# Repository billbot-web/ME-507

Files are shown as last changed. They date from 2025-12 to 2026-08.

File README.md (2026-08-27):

# SportTrackr: Camera-Guided Dual-Axis Tracking System

An ESP32-based real-time tracking system that combines computer vision, motion control, and web telemetry to automatically track LED targets using a camera-guided pan-tilt mechanism.

System Overview

## Project Overview

SportTrackr is an embedded control system designed for automated visual tracking applications. The system uses an OV5640 camera module for target detection, dual DC motors with encoders for precise pan-tilt control, and an IMU for orientation sensing. All components are coordinated through a FreeRTOS-based task architecture with PID control loops for smooth and accurate tracking.

### Key Features

- **Autonomous LED Tracking**: Real-time computer vision processing for target detection and tracking
- **Multi-Mode Operation**: Automatic tracking, manual control, velocity mode, and position mode
- **Web Interface**: Live telemetry streaming and remote control via WiFi
- **Precision Control**: Closed-loop PID control with encoder feedback
- **Sensor Fusion**: 9-DOF IMU integration for enhanced stability
- **Modular Architecture**: FSM-based task design for easy extension and debugging

## 📁 Repository Structure

```
├── data/              # Web UI assets (HTML, CSS, JavaScript)
├── docs/              # Doxygen-generated documentation
├── src/               # Source code
│   ├── hardware/      # Hardware drivers (motors, encoders, camera, IMU)
│   ├── tasks/         # FreeRTOS task implementations
│   ├── fsm/           # Finite state machine framework
│   └── main.cpp       # System initialization and setup
└── hardware/          # Physical design files
    ├── cad/           # Mechanical CAD files (SolidWorks)
    └── pcb/           # PCB design files (KiCad)
```

## System Components

### Hardware
- **MCU**: ESP32-WROVER (Dual-core, WiFi, 4MB PSRAM)
- **Camera**: OV5640 (5MP, autofocus, JPEG compression)
- **Motors**: 2× DC motors with 70:1 gearboxes
- **Drivers**: 2× DRV8833 dual H-bridge motor controllers
- **Encoders**: 2× Quadrature encoders (64 CPR)
- **IMU**: BNO055 (9-DOF: accelerometer, gyroscope, magnetometer)

### Software Stack
- **Framework**: Arduino/ESP-IDF on PlatformIO
- **RTOS**: FreeRTOS for multitasking
- **Web Server**: ESPAsyncWebServer for WiFi interface
- **Control**: Custom PID implementation with multiple tuning profiles

## Documentation

Detailed documentation is available for each subsystem:

- **[Mechanical Design](hardware/cad/README.md)** - CAD models, assemblies, and 3D-printed parts
- **[Electronic Design](hardware/pcb/README.md)** - PCB schematics, board layout, and wiring
- **[Software Architecture](src/README.md)** - Code organization and design patterns
  - [Hardware Drivers](src/hardware/README.md) - Low-level peripheral interfaces
  - [Task Controllers](src/tasks/README.md) - FreeRTOS task implementations
  - [FSM Framework](src/fsm/README.md) - State machine design pattern
- **[Web Interface](data/README.md)** - User interface and telemetry system
- **[API Reference](docs/html/index.html)** - Full Doxygen documentation

## Getting Started

### Prerequisites
- PlatformIO IDE (VS Code extension recommended)
- ESP32 toolchain
- USB-to-Serial driver for ESP32

### Build and Upload
```bash
# Clone the repository
git clone https://github.com/billbot-web/ME-507.git
cd ME-507

# Build the project
pio run

# Upload to ESP32
pio run --target upload

# Upload filesystem (web UI)
pio run --target uploadfs

# Monitor serial output
pio device monitor
```

### Configuration
1. Update WiFi credentials in `src/tasks/UITask.cpp`
2. Adjust PID tuning parameters in `src/main.cpp` (see comments for guidance)
3. Calibrate camera detection thresholds in `src/tasks/CameraTask.cpp`

## Operating Modes

The system supports four distinct operating modes:

1. **TRACKER**: Autonomous camera-based target tracking with PID control
2. **TELEOP**: Manual velocity control via web interface
3. **MOTOR_TEST**: Open-loop motor testing for diagnostics
4. **CALIBRATE**: Encoder homing and reference position setup

Modes are switched via the web interface or programmatically through the ControllerTask.

## System Architecture

The system uses a modular FreeRTOS task architecture:

- **MotorTask** (2 instances): Multi-mode motor control with FSM-based state management
- **EncoderTask** (2 instances): High-frequency position/velocity measurement using ESP32 PCNT
- **ControllerTask**: System coordinator and mode manager
- **CameraTask**: Computer vision processing for LED detection
- **IMUTask**: Orientation sensing and sensor data fusion
- **UITask**: Web server, telemetry streaming, and user commands

Tasks communicate via FreeRTOS queues and share data through thread-safe mechanisms.

## Performance

- **Control Loop Rate**: 100 Hz (10ms task periods)
- **Camera Frame Rate**: ~10-15 FPS (JPEG compression)
- **Encoder Resolution**: 4480 counts/revolution (with gearbox)
- **Position Accuracy**: ±0.5° typical
- **Latency**: <50ms from detection to motor response

## Contributors

- **Johnny Rourke** - Software, Integration, Mechanical Design & CAD
- **William Hawkins** - Software, Electronics & PCB Design

## License

This project was developed as part of ME 507 (Mechatronics) at California Polytechnic State University, San Luis Obispo.

## 🔗 Additional Resources

- [Doxygen Documentation](docs/html/index.html) - Complete API reference
- [FSM Design Pattern](src/fsm/FSM.md) - State machine implementation details
- [PID Tuning Guide](src/main.cpp) - Controller configuration instructions

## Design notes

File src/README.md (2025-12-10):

# Software Architecture

This directory contains all source code for the SportTrackr embedded control system, organized into three main subsystems: hardware drivers, FreeRTOS tasks, and FSM framework.

## Directory Structure

```
src/
├── hardware/          # Low-level peripheral drivers
│   ├── DRV883.cpp/h           - Motor driver interface
│   ├── Encoder.cpp/h          - Quadrature encoder driver
│   ├── OV5640_camera.cpp/h    - Camera module interface
│   └── Adafruit_BNO055.cpp/h  - IMU sensor driver
├── tasks/             # FreeRTOS task controllers
│   ├── MotorTask.cpp/h        - Multi-mode motor control FSM
│   ├── EncoderTask.cpp/h      - Position/velocity measurement
│   ├── CameraTask.cpp/h       - Computer vision processing
│   ├── ControllerTask.cpp/h   - System coordinator
│   ├── UITask.cpp/h           - Web server & telemetry
│   └── IMU_TASK.cpp/h         - Inertial measurement
├── fsm/               # Finite state machine framework
│   ├── FSM.cpp/h              - State machine engine
│   ├── State.h                - State base class
│   └── FSM.md                 - Design documentation
└── main.cpp           # System initialization & setup
```
## Task Diagram
SportTrackr_TaskDiagram
## Inter-Task Communication

### Queue-Based Messaging and Shares, a length-one Queue
See the provided ME 507 library for more information
```cpp
// Create queues in main.cpp
QueueHandle_t motor_cmd_queue = xQueueCreate(10, sizeof(MotorCommand));
QueueHandle_t tracking_error_queue = xQueueCreate(5, sizeof(TrackingError));

// Producer (CameraTask)
TrackingError error;
error.x_error = led_x - FRAME_CENTER_X;
error.y_error = led_y - FRAME_CENTER_Y;
xQueueSend(tracking_error_queue, &error, 0);

// Consumer (MotorTask)
TrackingError error;
if (xQueueReceive(tracking_error_queue, &error, 0) == pdTRUE) {
    set_target_position(current_pos + error.x_error);
}
```

## Architecture Overview

### Design Philosophy
The system follows a **modular, task-based architecture** using FreeRTOS for concurrency and finite state machines for complex behavioral control. Each major subsystem runs as an independent task with well-defined responsibilities and communication interfaces.

### Key Principles
- **Separation of Concerns**: Hardware drivers are isolated from application logic
- **State-Driven Behavior**: Complex control modes managed via FSM pattern
- **Thread-Safe Communication**: FreeRTOS queues and shared data structures
- **Real-Time Responsiveness**: Fixed-period tasks with predictable timing
- **Modularity**: Easy to add/remove features without affecting other subsystems

## System Components

### 1. Hardware Drivers (`hardware/`)
Low-level peripheral interfaces providing abstraction over ESP32 hardware features.

**[Full Hardware Documentation →](hardware/README.md)**

- **DRV883**: H-bridge motor driver control (PWM, direction, sleep)
- **Encoder**: PCNT-based quadrature decoder for position/velocity
- **OV5640_camera**: Image capture, JPEG compression, LED detection
- **Adafruit_BNO055**: 9-DOF IMU with sensor fusion

### 2. Task Controllers (`tasks/`)
FreeRTOS tasks implementing system behaviors and coordination.

**[Full Task Documentation →](tasks/README.md)**

- **MotorTask**: FSM-based motor control (velocity, position, camera, test modes)
- **EncoderTask**: High-frequency encoder sampling and velocity estimation
- **CameraTask**: LED blob detection and visual servoing error computation
- **ControllerTask**: Global mode management and task coordination
- **UITask**: Web server, WebSocket telemetry, command processing
- **IMU_TASK**: Orientation sensing and motion data acquisition

### 3. FSM Framework (`fsm/`)
Reusable finite state machine implementation for behavioral control.

**[Full FSM Documentation →](fsm/README.md)**

- **FSM**: Execute-driven state machine engine
- **State**: Base class for state definitions
- **Usage**: Task behaviors modeled as state transitions

## 🔄 Data Flow

```
┌─────────────┐         ┌──────────────┐         ┌─────────────┐
│   Camera    │────────▶│  CameraTask  │────────▶│  MotorTask  │
│   (OV5640)  │  Image  │  (CV Loop)   │ Error   │  (Control)  │
└─────────────┘         └──────────────┘         └─────────────┘
                                                         │
                                                         │ PWM
                                                         ▼
┌─────────────┐         ┌──────────────┐         ┌─────────────┐
│   Encoder   │◀────────│ EncoderTask  │◀────────│  DRV8833    │
│   (PCNT)    │Position │ (Feedback)   │         │  (Driver)   │
└─────────────┘         └──────────────┘         └─────────────┘
                               │
                               │ Telemetry
                               ▼
┌─────────────┐         ┌──────────────┐         ┌─────────────┐
│   WiFi      │◀────────│   UITask     │◀────────│ Controller  │
│  (WebUI)    │WebSocket│  (Server)    │Commands │   Task      │
└─────────────┘         └──────────────┘         └─────────────┘
```

## Development Guide

### Building the Project
```bash
# Full build
pio run

# Upload firmware
pio run --target upload

# Upload web interface files
pio run --target uploadfs

# Serial monitor
pio device monitor
```

### Code Style
- **Doxygen Comments**: All functions, classes, and files documented
- **Naming Conventions**: 
  - Classes: `PascalCase`
  - Functions: `snake_case()`
  - Constants: `UPPER_SNAKE_CASE`
- **Indentation**: 4 spaces (no tabs)
- **Line Length**: 100 characters recommended

### Adding New Features

#### 1. New Hardware Driver
```cpp
// In src/hardware/NewDriver.h
class NewDriver {
public:
    NewDriver(int pin);
    void init();
    int read();
};

// Register in main.cpp
NewDriver driver(GPIO_PIN);
driver.init();
```

#### 2. New Task
```cpp
// In src/tasks/NewTask.h
class NewTask : public Task {
public:
    NewTask(const char* name, uint32_t stack, uint8_t priority);
    void run(void* params) override;
};

// Create in main.cpp
NewTask* newTask = new NewTask("NewTask", 4096, 3);
newTask->begin();
```

#### 3. New FSM State
```cpp
// Define state function
int new_state_execute() {
    // State behavior
    return NEXT_STATE_ID;  // or same ID to stay
}

// Add to state table
State newState(STATE_ID, "NEW_STATE", new_state_execute);
State* states[] = {&state0, &newState, ...};
```

## Debugging

### Serial Debugging
```cpp
Serial.println("Debug message");
Serial.printf("Value: %d\n", variable);
```

### Task Monitoring
```cpp
// In any task
void run(void* params) {
    while (1) {
        Serial.printf("[%s] Running at %lu\n", 
                      pcTaskGetName(NULL), 
                      xTaskGetTickCount());
        vTaskDelay(pdMS_TO_TICKS(10));
    }
}
```

### Common Issues

**Task Crashes**
- Increase stack size in task constructor
- Check for stack overflow with `uxTaskGetStackHighWaterMark()`
- Verify no blocking operations in ISRs

**Queue Overflows**
- Increase queue depth when creating
- Check consumer task is reading fast enough
- Add queue full error handling

**Timing Issues**
- Use `vTaskDelay()` not `delay()` in tasks
- Verify task priorities are appropriate
- Check for priority inversion on shared resources

## 📊 Performance Metrics

- **Control Loop**: 100 Hz (10ms period)
- **Camera Processing**: ~15 FPS
- **Encoder Sampling**: 1000 Hz
- **WebSocket Updates**: 10 Hz
- **CPU Utilization**: ~60% average (dual-core)
- **Memory Usage**: ~180KB RAM (PSRAM for camera)

## 🔧 Configuration

### WiFi Settings
Edit `src/tasks/UITask.cpp`:
```cpp
const char* ssid = "YourNetworkName";
const char* password = "YourPassword";
```

### PID Tuning
Edit `src/main.cpp`:
```cpp
// Position control
pidKp = 0.5f;
pidKi = 0.0f;
pidKd = 0.1f;

// Camera tracking
pidKp_cam = 0.3f;
pidKi_cam = 0.0f;
pidKd_cam = 0.05f;
```

### Camera Detection
Edit `src/tasks/CameraTask.cpp`:
```cpp
// HSV thresholds for LED detection
int hue_min = 160;
int hue_max = 180;
int sat_min = 100;
int val_min = 100;
```

## API Documentation

Complete Doxygen-generated API documentation is available at:
**[docs/html/index.html](../docs/html/index.html)**

Key documentation sections:
- Class hierarchy and inheritance
- Function prototypes and parameters
- File dependencies and includes
- Global variables and defines

## Testing

### Unit Testing
(Future: Add unit test framework)

### Integration Testing
1. **Motor Test Mode**: Verify PWM outputs and direction control
2. **Encoder Test**: Check position counting and velocity calculation
3. **Camera Test**: Validate LED detection accuracy
4. **Network Test**: Confirm WiFi connectivity and WebSocket streaming

### System Validation
- Run full tracking demo
- Verify mode transitions
- Check error handling and recovery
- Measure control loop timing

## Safety Features

- **Watchdog Timer**: Reset on task deadlock
- **Motor Current Limiting**: DRV8833 thermal protection
- **Bounds Checking**: Encoder position limits
- **Command Validation**: Web interface input sanitization
- **Fault Recovery**: Automatic restart on critical errors

## Support

For software architecture questions, implementation details, or bug reports:
- Review existing [Doxygen documentation](../docs/html/index.html)
- Check [FSM design patterns](fsm/FSM.md)
- See specific subsystem READMEs:
  - [Hardware Drivers](hardware/README.md)
  - [Task Controllers](tasks/README.md)
  - [FSM Framework](fsm/README.md)

## Future Enhancements

Potential improvements and extensions:
- [ ] Kalman filter for sensor fusion
- [ ] Design a better IR Transmitter
- [ ] Smooth the pan and tilt error from the camera
- [ ] Machine learning-based detection
- [ ] Bluetooth remote control
- [ ] SD card data logging
- [ ] OTA firmware updates
- [ ] Enhanced calibration routines

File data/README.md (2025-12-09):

# Web User Interface

This directory contains all web interface assets for the SportTrackr remote control and telemetry system. The UI provides real-time monitoring, manual control, and system configuration through a responsive web interface served by the ESP32.

## 📂 Directory Structure

```
data/
├── index.html         # Main web application
├── css/
│   └── style.css     # Styling and layout
└── js/
    └── app.js        # Client-side JavaScript logic
```

## 🌐 Overview

The SportTrackr web interface is a single-page application (SPA) that communicates with the ESP32 over WiFi using HTTP for initial page load and WebSockets for real-time bidirectional communication.

### Features
- **Live Telemetry Dashboard**: Real-time display of motor positions, velocities, IMU data
- **Mode Selection**: Switch between tracking, teleop, motor test, and calibration modes
- **Manual Control**: Velocity joystick control for pan/tilt motors
- **Camera Stream**: Live video feed from OV5640 camera (JPEG over HTTP)
- **PID Configuration**: Adjust controller gains on-the-fly
- **System Status**: Connection state, error messages, diagnostics

## 🎨 User Interface Layout

### Header Section
- System title and logo
- Connection status indicator
- Mode selection dropdown

### Main Dashboard (Grid Layout)

#### Left Panel - Camera View
- Live video stream display
- Crosshair overlay showing target position
- Frame rate and resolution info
- LED detection visual feedback

#### Center Panel - Telemetry
Real-time numeric displays:
- **Motor Positions**: Pan/tilt encoder counts
- **Motor Velocities**: Current speed in counts/sec
- **IMU Orientation**: Euler angles (roll, pitch, yaw)
- **Tracking Error**: X/Y pixel error from target
- **System Time**: Uptime and cycle count

#### Right Panel - Controls
- **Mode Buttons**: 
  - 🎯 TRACKER - Auto tracking
  - 🕹️ TELEOP - Manual control
  - 🔧 MOTOR_TEST - Diagnostics
  - 📐 CALIBRATE - Homing
- **Joystick Control**: Touch/mouse velocity input
- **PID Tuning Sliders**: Kp, Ki, Kd adjustment
- **Emergency Stop**: Immediate motor shutdown

### Footer Section
- WebSocket connection state
- Data rate (messages/sec)
- Latency indicator
- Help/documentation link

## 🔌 Communication Protocol

### WebSocket Message Format

#### Client → Server (Commands)
```json
{
    "type": "command",
    "action": "set_mode",
    "value": "TRACKER"
}

{
    "type": "joystick",
    "pan_velocity": 50,
    "tilt_velocity": -30
}

{
    "type": "pid_update",
    "kp": 0.5,
    "ki": 0.0,
    "kd": 0.1
}
```

#### Server → Client (Telemetry)
```json
{
    "type": "telemetry",
    "timestamp": 1234567890,
    "pan_position": 2000,
    "tilt_position": -500,
    "pan_velocity": 120,
    "tilt_velocity": -80,
    "imu_roll": 2.5,
    "imu_pitch": -1.2,
    "imu_yaw": 45.7,
    "tracking_error_x": 15,
    "tracking_error_y": -22,
    "current_mode": "TRACKER"
}
```

### HTTP Endpoints

- **GET /** - Serve main HTML page
- **GET /style.css** - Serve stylesheet
- **GET /app.js** - Serve JavaScript
- **GET /stream** - MJPEG camera stream
- **GET /status** - JSON system status
- **POST /config** - Update configuration

## 💻 JavaScript Architecture (`app.js`)

### Core Components

#### WebSocket Manager
```javascript
class WebSocketManager {
    connect()           // Establish WebSocket connection
    send(message)       // Send JSON command
    onMessage(handler)  // Register message callback
    reconnect()         // Auto-reconnect on disconnect
}
```

#### Telemetry Display
```javascript
class TelemetryDisplay {
    update(data)        // Refresh all UI elements
    formatValue(val)    // Format numbers for display
    updateGraph(data)   // Update real-time plots
}
```

#### Control Input
```javascript
class JoystickControl {
    init(canvas)        // Initialize touch canvas
    onMove(callback)    // Register movement handler
    getVelocity()       // Get current X/Y values
    reset()             // Return to center
}
```

#### Mode Controller
```javascript
class ModeController {
    setMode(mode)       // Request mode change
    getCurrentMode()    // Get active mode
    validateTransition() // Check if mode switch allowed
}
```

### Event Handlers

```javascript
// WebSocket connection established
ws.onopen = () => {
    console.log("Connected to SportTrackr");
    startTelemetry();
};

// Incoming telemetry data
ws.onmessage = (event) => {
    const data = JSON.parse(event.data);
    updateDashboard(data);
};

// User clicks mode button
document.getElementById('mode-tracker').onclick = () => {
    sendCommand({type: 'set_mode', value: 'TRACKER'});
};

// Joystick movement
joystick.onMove = (x, y) => {
    sendCommand({
        type: 'joystick',
        pan_velocity: x * 100,
        tilt_velocity: y * 100
    });
};
```

## 🎨 Styling (`style.css`)

### Design System

**Color Palette:**
- Primary: `#2196F3` (Blue)
- Success: `#4CAF50` (Green)
- Warning: `#FF9800` (Orange)
- Danger: `#F44336` (Red)
- Background: `#1E1E1E` (Dark)
- Text: `#FFFFFF` (White)

**Typography:**
- Headings: `Roboto, sans-serif`
- Body: `Arial, sans-serif`
- Monospace: `Consolas, monospace`

**Layout:**
- CSS Grid for main dashboard
- Flexbox for controls and buttons
- Responsive breakpoints at 768px, 1024px

### Key Classes

```css
.dashboard-grid {
    display: grid;
    grid-template-columns: 1fr 1fr 1fr;
    gap: 20px;
}

.telemetry-card {
    background: #2C2C2C;
    border-radius: 8px;
    padding: 15px;
    box-shadow: 0 2px 4px rgba(0,0,0,0.3);
}

.mode-button {
    padding: 12px 24px;
    border-radius: 4px;
    transition: all 0.3s ease;
}

.mode-button.active {
    background: #4CAF50;
    box-shadow: 0 0 10px rgba(76, 175, 80, 0.5);
}
```

## 📱 Responsive Design

### Desktop (>1024px)
- Three-column grid layout
- Full camera stream size
- All controls visible simultaneously

### Tablet (768px - 1024px)
- Two-column grid
- Stacked control panels
- Reduced camera resolution

### Mobile (<768px)
- Single column layout
- Collapsible panels
- Touch-optimized controls
- Simplified joystick

## 🚀 Deployment

### Upload to ESP32
```bash
# Using PlatformIO
pio run --target uploadfs

# Or using esptool
esptool.py --chip esp32 --port COM4 write_flash 0x291000 spiffs.bin
```

### File System
Files are stored in ESP32 SPIFFS (SPI Flash File System):
- Total Size: 1.5MB
- Used: ~50KB (HTML/CSS/JS)
- Available: ~1.45MB for future assets

### Optimization
- Minify JavaScript/CSS for production
- Compress images (if added)
- Use gzip compression on server
- Cache static assets

## 🔧 Configuration

### WiFi Settings
Set in `src/tasks/UITask.cpp`:
```cpp
const char* ssid = "YourNetwork";
const char* password = "YourPassword";
IPAddress local_IP(192, 168, 1, 100);  // Optional static IP
```

### WebSocket Port
Default: 80 (HTTP) with WebSocket upgrade

### Access URL
After connecting to WiFi:
```
http://192.168.1.100/         (if static IP)
http://sporttrackr.local/     (if mDNS enabled)
```

## 🐛 Debugging

### Browser Console
```javascript
// Enable verbose logging
localStorage.setItem('debug', 'true');

// Monitor WebSocket messages
ws.onmessage = (e) => {
    console.log('RX:', e.data);
};
```

### Common Issues

**WebSocket won't connect:**
- Check ESP32 IP address
- Verify firewall settings
- Ensure WebSocket port is open
- Try different browser

**Telemetry not updating:**
- Check WebSocket connection state
- Verify JSON parsing (check console)
- Confirm UITask is running on ESP32
- Check telemetry update rate in firmware

**Camera stream blank:**
- Verify camera initialization
- Check HTTP endpoint `/stream`
- Ensure sufficient PSRAM for JPEG buffer
- Try lower resolution setting

## 🎯 Performance

### Metrics
- **Initial Load Time**: <2 seconds
- **WebSocket Latency**: 20-50ms
- **Telemetry Update Rate**: 10 Hz (100ms interval)
- **UI Refresh Rate**: 60 FPS (CSS animations)
- **Camera FPS**: 10-15 (depends on resolution)

### Optimization Tips
- Throttle joystick events (max 20 Hz)
- Batch telemetry updates
- Use CSS transforms for smooth animations
- Debounce PID slider inputs

## 🔐 Security Considerations

### Current Implementation
- **No authentication** - Open access on local network
- **No encryption** - Plain HTTP/WebSocket
- **No input validation** - Trust client data

### Future Enhancements
- [ ] Basic authentication (username/password)
- [ ] HTTPS/WSS with self-signed certificate
- [ ] Command rate limiting
- [ ] Input sanitization on server side
- [ ] Session management
- [ ] CORS configuration

## 📚 Related Documentation

- [UITask Implementation](../src/tasks/README.md#uitask) - Server-side code
- [Software Architecture](../src/README.md) - Overall system design
- [System Overview](../README.md) - Project documentation

## 🚀 Future Features

Planned UI enhancements:
- [ ] Real-time plotting (position/velocity graphs)
- [ ] Recording and playback of tracking sessions
- [ ] Multiple camera view support
- [ ] Advanced PID auto-tuning wizard
- [ ] Diagnostic logs viewer
- [ ] Mobile app (React Native or Flutter)
- [ ] Dark/light theme toggle
- [ ] Multi-language support

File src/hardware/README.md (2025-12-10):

# Hardware Drivers

These Low-level drivers provide abstraction to easily and repeatably interface with multiple hardware peripherals using the ESP32. These drivers include applications for motor control, sensing, and vision.

## 📂 Files

- **DRV883.cpp/h** - DRV8833 dual H-bridge motor driver control
- **Encoder.cpp/h** - Quadrature encoder interface using ESP32 PCNT
- **OV5640_camera.cpp/h** - OV5640 camera module with JPEG capture
- **Adafruit_BNO055.cpp/h** - BNO055 9-DOF IMU sensor driver. This is an Open-source driver for more information see https://github.com/adafruit/Adafruit_BNO055.git

## 🔌 DRV883 Motor Driver

### Overview
Interface to the DRV8833 dual H-bridge motor driver providing PWM speed control and direction control. This driver takes in four input parameters: the first two are the two pins on the ESP32 that you will use for PWM. To control the motor speed and direction, the other two are the corresponding PWM channels for the in1 and in2 pins, respectively. When setting the motor PWM effort, the input is meant in the range of -100 to 100. The PWM Effort represents the ratio of how often the motor is on compared with simply being turned on, and the negative is meant to represent turning in either direction. We currently clamp the input effort in code to the possible range, so you can input efforts outside this range, and it will automatically saturate the motor.

### Key Features
- **Dual PWM outputs** with configurable frequency (20kHz default)
- **Direction control** via IN1/IN2 pins (forward, reverse, brake, coast)

[1]
The Disable pin is tied high internally. While the nSleep pin is shared for both motors so it is handled outside of the motor driver.
- **Current limiting** via hardware (1.5A continuous, 5A peak)

### API
```cpp
 DRV883(int in1, int in2, int ledcCh1, int ledcCh2,
                uint32_t pwmFreq = 20000, uint8_t resolutionBits = 10);
    void set_eff(int effort);
    void stop();
    void brake();

```

### Usage Example
```cpp
DRV883 motor(GPIO32, GPIO33, GPIO25, GPIO26);

motor.set_eff(90);    // Half speed forward
motor.set_eff(-100);   // Fast reverse
motor.brake();           // Stop immediately
```

## 📐 Encoder Driver

### Overview
Quadrature encoder interface using ESP32 PCNT (Pulse Counter) peripheral for high-frequency, hardware-based position tracking.

### Key Features
- **Hardware counting** (no CPU overhead)
- **Quadrature decoding** (4× resolution enhancement)
- **Velocity estimation** via position differentiation
- **16-bit signed counter** with overflow handling
- **Up to 40MHz counting** frequency support
- **High Resolution** 32 counts per revolution of the motor, multiplied by the 70:1 Gear ratio to the output shaft, so 2240 counts per revolution for the output shaft.

### API
```cpp
class Encoder {
public:
    Encoder(int pinA, int pinB, pcnt_unit_t unit);
    void init();                    // Configure PCNT unit
    int32_t get_position();         // Read current count
    float get_velocity();           // Estimate speed (counts/sec)
    void zero();                   // Zero the counter
};
```

### Usage Example
```cpp
Encoder encoder(GPIO34, GPIO35, PCNT_UNIT_0);
encoder.init();

int32_t pos = encoder.get_position();
float vel = encoder.get_velocity();
encoder.zero();  // Re-home to zero
```

### Hardware Connections
| Encoder | Channel A | Channel B | PCNT Unit |
|---|---|---|---|
| Pan | GPIO01 | GPIO03 | UNIT_0 |
| Tilt | GPIO14 | GPIO19 | UNIT_1 |

### Resolution Calculation
```
Base Resolution: 32 CPR (counts per revolution)
Gear Ratio: 70:1
Total: 32 × 70 = 2240 counts/motor_revolution
Final: 2240 counts per output shaft revolution (after gearbox)
```

## 📷 OV5640 Camera Driver

### Overview
Interface to OV5640 5-megapixel camera module with autofocus, providing JPEG-compressed image capture and LED blob detection. This allows for position and velocity tracking of both motors in the design. We only directly measure the angular position we move, so we need to divide by the time step between data points to determine the motor velocity. This can become inaccurate at low speeds. In order to smooth the velocity output, we also implemented a 5-position and 5 time-step buffer in order to average the encoder velocity over the past five data points to reduce noise. This also allows for closed-loop control on both motors.

### Key Features
- **High resolution**: Up to 2592×1944 (5MP)
- **Configurable formats**: JPEG, RGB565, YUV422
- **Autofocus control**: Software-triggered AF
- **JPEG compression**: Hardware JPEG encoder
- **LED detection**: HSV color-space blob tracking
- **Frame buffering**: PSRAM-based DMA transfers

### API
```cpp
class OV5640_camera {
public:
    OV5640_camera();
    bool init(framesize_t size);           // Initialize with resolution
    bool capture();                        // Capture single frame
    uint8_t* get_fb();                     // Get frame buffer pointer
    size_t get_fb_len();                   // Get frame size in bytes
    bool detect_led(int* x, int* y);       // Find LED centroid
    void set_hsv_threshold(int h_min, int h_max, 
                           int s_min, int v_min);
    void autofocus();                      // Trigger autofocus
};
```

### Usage Example
```cpp
OV5640_camera cam;
cam.init(FRAMESIZE_VGA);  // 640×480
cam.set_hsv_threshold(160, 180, 100, 100);  // Red LED

if (cam.capture()) {
    int led_x, led_y;
    if (cam.detect_led(&led_x, &led_y)) {
        Serial.printf("LED at (%d, %d)\n", led_x, led_y);
    }
    
    uint8_t* jpeg = cam.get_fb();
    size_t len = cam.get_fb_len();
    // Send JPEG data...
}
```

### Hardware Connections (SCCB + Parallel)
| Signal | GPIO | Description |
|---|---|---|
| SDA | 21 | I2C data (SCCB) |
| SCL | 22 | I2C clock (SCCB) |
| D0-D7  | 4-5, 18-19, 36-39 | Parallel data bus |
| VSYNC  | 23 | Vertical sync |
| HREF | 25 | Horizontal reference |
| PCLK | 22 | Pixel clock |

### Detection Algorithm
1. Convert RGB → HSV color space
2. Threshold by hue/saturation/value ranges
3. Find the largest contiguous blob
4. Calculate centroid (weighted average)
5. Return pixel coordinates (0,0 = center)

## Adafruit_BNO055 IMU Driver

### Overview
Interface to BNO055 9-DOF absolute orientation sensor providing fused accelerometer, gyroscope, and magnetometer data.

### Key Features
- **Sensor fusion**: Onboard ARM Cortex M0+ processor
- **Absolute orientation**: Quaternion and Euler angle output
- **9 degrees of freedom**: 3-axis accel + gyro + mag
- **Automatic calibration**: Self-calibrating sensors
- **Fast I2C**: Up to 400kHz bus speed

### API
```cpp
class Adafruit_BNO055 {
public:
    Adafruit_BNO055(int32_t id, uint8_t address);
    bool begin();                          // Initialize sensor
    void setMode(adafruit_bno055_opmode_t mode);
    imu::Vector<3> getVector(vector_type_t type);
    uint8_t getCalibration();              // Get cal status (0-3)
    void getQuat(double* w, double* x, double* y, double* z);
    void getEuler(double* roll, double* pitch, double* yaw);
};
```

### Usage Example
```cpp
Adafruit_BNO055 bno(55, 0x28);  // ID=55, I2C addr=0x28
if (bno.begin()) {
    bno.setMode(OPERATION_MODE_NDOF);  // 9-DOF fusion
    
    // Read orientation
    double roll, pitch, yaw;
    bno.getEuler(&roll, &pitch, &yaw);
    
    // Check calibration (0=uncal, 3=fully calibrated)
    uint8_t cal = bno.getCalibration();
    if (cal >= 2) {
        Serial.println("IMU calibrated");
    }
    
    // Read raw sensors
    imu::Vector<3> accel = bno.getVector(VECTOR_ACCELEROMETER);
    imu::Vector<3> gyro = bno.getVector(VECTOR_GYROSCOPE);
}
```

### Hardware Connections
| Signal | GPIO | Description |
|---|---|---|
| SDA | 21 | I2C data (shared with camera) |
| SCL | 22 | I2C clock (shared with camera) |

### Coordinate System
- **X-axis**: Forward (pitch rotation)
- **Y-axis**: Left (roll rotation)
- **Z-axis**: Up (yaw rotation)
- **Euler Angles**: Roll (±180°), Pitch (±90°), Yaw (0-360°)

### Calibration Process
1. **Gyroscope**: Keep sensor stationary (auto-calibrates in ~1s)
2. **Accelerometer**: Rotate through all 6 faces (cube orientation)
3. **Magnetometer**: Move in figure-8 pattern (avoid magnetic interference)
4. **System**: Wait for all sensors to reach calibration level 3

## 🔧 Common Patterns

### Initialization Sequence
```cpp
void setup() {
     // ----------------Pan Motor pins ----------------
   #define PanIN1 GPIO_NUM_2
   #define PanIN2 GPIO_NUM_5
   #define nSLP_PIN GPIO_NUM_13
   // ---------------- Pan Encoder pins/unit ----------------
   #define TiltENCODER_A_GPIO GPIO_NUM_14
   #define TiltENCODER_B_GPIO GPIO_NUM_19
   #define TiltENCODER_UNIT   PCNT_UNIT_0
   // ----------------Tilt Motor pins ----------------
   #define TiltIN1 GPIO_NUM_18
   #define TiltIN2 GPIO_NUM_23
   // ---------------- Tilt Encoder pins/unit ----------------
   #define PanENCODER_A_GPIO GPIO_NUM_3
   #define PanENCODER_B_GPIO GPIO_NUM_1 //should be GPI01
   #define PanENCODER_UNIT   PCNT_UNIT_1
  // Set I2C pins for ESP32
  I2C.setPins(21, 22);
  Serial.println("=== SporTrackr IMU Data Reader ===");
  Serial.println("Initializing IMU...");
  
  // Initialize and start IMU task
  if (imuTask.initIMU()) {
    Serial.println("IMU initialized successfully!");
    delay(300);
    
    // Load saved calibration offsets automatically
    Serial.println("Loading saved calibration offsets...");
    imuTask.loadSavedCalibration();
  } else {
    Serial.println("WARNING: IMU initialization failed!");
    Serial.println("Continuing without IMU...");
  }
  
  // -------------------------------------------------------------------------
  // Step 6: Initialize OV5640 Camera Module
  // -------------------------------------------------------------------------
  
  // Camera initialization - skip if it fails (GPIO conflicts)
  bool camera_ok = camera.begin();
  if (!camera_ok) {
    Serial.println("WARNING: Camera initialization failed!");
    Serial.println("Continuing without camera...");
  } else {
    Serial.println("Camera initialized successfully");
  }
```

## Troubleshooting

### Motor Driver Issues
- **Motor not spinning**: Check PWM frequency, verify sleep pin HIGH
- **Thermal shutdown**: Reduce current, add heatsink, check for stall
- **Erratic behavior**: Add decoupling capacitors, check power supply

### Camera Issues
- **Init failure**: Check I2C address (0x3C), verify SCCB communication
- **Black frames**: Ensure HREF/VSYNC connected, check clock signals
- **Detection fails**: Tune HSV thresholds, improve lighting conditions

### IMU Issues
- **No response**: Verify I2C address (0x28 or 0x29), check power
- **Poor calibration**: Avoid magnetic interference, perform cal routine
- **Data jumps**: Filter outliers, use sensor fusion quaternions

## Related Documentation

- [Task Controllers](../tasks/README.md) - Higher-level task implementations
- [Software Architecture](../README.md) - System overview
- [PCB Design](../../hardware/pcb/README.md) - Hardware connections

## Datasheets

- 1. [DRV8833 Datasheet](https://www.ti.com/lit/ds/symlink/drv8833.pdf)
- 2. [OV5640 Datasheet](https://cdn.sparkfun.com/datasheets/Sensors/LightImaging/OV5640_datasheet.pdf)
- 3. [BNO055 Datasheet](https://www.bosch-sensortec.com/media/boschsensortec/downloads/datasheets/bst-bno055-ds000.pdf)
- 4. [ESP32 PCNT Documentation](https://docs.espressif.com/projects/esp-idf/en/latest/esp32/api-reference/peripherals/pcnt.html)

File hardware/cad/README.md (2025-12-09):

# Mechanical Design - CAD Files

This directory contains all mechanical design files for the SportTrackr pan-tilt tracking system, including SolidWorks assemblies, part models, and 3D-printable components.

## 📂 Directory Structure

```
cad/
├── ElectricalParts/        # Electronics housing and mounts
├── MechanicalParts/        # Mechanical components (gears, shafts, bearings)
├── Phone_Assembly/         # Camera/phone mounting system
├── Printed Parts/          # 3D-printable components
│   ├── STLs/               # Print-ready STL files
│   └── GCODE/              # Pre-sliced G-code files
└── SportTrackr_Assembly.SLDASM  # Complete system assembly
```

## 🔩 Key Components

### Printed Parts
All 3D-printed parts are designed for FDM printing with PLA material:

- **Base.SLDPRT** - Main mounting platform
- **Tilt_Mount.SLDPRT** - Tilt axis motor mount
- **Tilt_Camera_Mount.SLDPRT** - Camera bracket for tilt mechanism
- **Test_motorMount.SLDPRT** - Motor mounting bracket
- **IRFilterMount.SLDPRT** - IR filter holder for camera
- **Filtermountcover.SLDPRT** - Protective cover for filter
- **Housing2.SLDPRT** - Electronics enclosure
- **base mount.SLDPRT** - Base attachment point

**Print Settings:**
- Layer Height: 0.15mm
- Nozzle: 0.4mm
- Infill: 20-30%
- Supports: Required for some parts (see STL orientation)

### Mechanical Components

#### Power Transmission
- **30 THEETH 32MM GEAR.SLDPRT** - Main drive gear (30T, 32mm OD)
- **GT2 Pulley 20 Tooth.SLDPRT** - Timing belt pulley (20T, 6mm bore)
- **GT2_20T-sh8.SLDPRT** - Timing belt pulley (20T, 8mm bore)

#### Shafts & Bearings
- **Shaft.SLDPRT** - Main drive shaft (custom machined)
- **Shaft_Coupler.SLDPRT** - Flexible shaft coupling
- **FlangedShaft_Collar.SLDPRT** - Shaft retention collar
- **8mm Bearing Mount.SLDPRT** - Bearing housing

### Electrical Components
CAD models for electronics integration:

- **ESP32.SLDPRT** - ESP32-WROVER module model
- **ESP32_BAT.SLDPRT** - ESP32 with battery pack
- **OV5640.SLDPRT** - Camera module model
- **Motor.SLDPRT** - DC gearmotor model
- **MotorBat.SLDPRT** - Motor with power connections
- **sport_trackr_PCB.SLDASM** - Custom PCB assembly

### Phone/Camera Assembly
Alternative mounting system for smartphone camera:

- **Phone_Assembly.SLDASM** - Complete phone mounting assembly
- **Phone_Mount.SLDPRT** - Primary phone bracket
- **Phone_Mount2.SLDPRT** - Secondary mounting option
- **phone.SLDPRT** - Phone reference model

## 🔧 Assembly Instructions

1. **Print all parts** from `Printed Parts/STLs/` directory
2. **Mechanical assembly**:
   - Install bearings in bearing mounts
   - Insert shaft through tilt mechanism
   - Attach motors to motor mounts
   - Install gears/pulleys on motor shafts
   - Secure with shaft collars
3. **Electronics integration**:
   - Mount ESP32 board in housing
   - Attach camera to camera mount
   - Install PCB in base enclosure
   - Route wiring through cable channels
4. **Final assembly**:
   - Attach tilt mechanism to base
   - Mount pan motor to base plate
   - Connect all electrical connections
   - Secure covers and protective housings

## 📐 Design Specifications

- **Total Height**: ~250mm (assembled)
- **Base Footprint**: ~150mm × 150mm
- **Tilt Range**: ±45° (mechanical stops)
- **Pan Range**: 360° continuous rotation
- **Weight**: ~800g (with electronics)
- **Material**: PLA plastic + aluminum shaft

## 🛠️ Required Hardware

### Fasteners
- M3 screws (various lengths: 6mm, 8mm, 12mm, 20mm)
- M3 heat-set inserts (20×)
- M4 screws for motor mounting (8×)
- M2 screws for PCB mounting (4×)

### Mechanical
- 8mm diameter steel shaft (150mm length)
- 608 bearings (2×)
- GT2 timing belt (200mm)
- Shaft couplers (2×)

### Electronics (see [PCB README](../pcb/README.md))

## 📄 File Formats

- **.SLDPRT** - SolidWorks part files (editable)
- **.SLDASM** - SolidWorks assembly files (editable)
- **.SLDDRW** - SolidWorks drawing files (fabrication reference)
- **.STL** - Stereolithography files (3D printing)
- **.STEP** - Universal CAD exchange format (available on request)

## 🖨️ 3D Printing Notes

Pre-sliced G-code files are available in `Printed Parts/GCODE/` for Prusa Mini+ printer. For other printers, import STL files into your slicer with these recommended settings:

- **Material**: PLA or PETG
- **Layer Height**: 0.15mm (quality) or 0.2mm (speed)
- **Wall Count**: 3-4 perimeters
- **Infill**: 20-30% gyroid or cubic
- **Supports**: Tree supports for overhangs >45°
- **Adhesion**: Brim for tall/narrow parts

Total print time: ~24 hours for complete set

## 🔄 Modification Guidelines

When modifying designs:
1. Maintain mounting hole patterns for compatibility
2. Preserve critical dimensions for motor/bearing fits
3. Update assembly file after part changes
4. Regenerate STL files after edits
5. Test-fit before full assembly

## 📞 Design Contact

For questions about mechanical design or part modifications, contact the mechanical design team member or refer to the main project repository.

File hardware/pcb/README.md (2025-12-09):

# Electronic Design - PCB Files

This directory contains all electronic design files for the SportTrackr system PCB, including schematics, board layout, and manufacturing files.

## 📂 Files

- **sport_trackr_copy.kicad_pro** - KiCad project file
- **sport_trackr_copy.kicad_sch** - Schematic diagram
- **sport_trackr_copy.kicad_pcb** - PCB layout (board design)
- **sport_trackr_copy.kicad_prl** - Project local settings
- **READ_ME** - Original design notes

## 🔌 PCB Overview

The SportTrackr PCB is a custom-designed control board that interfaces the ESP32-WROVER module with all peripheral hardware including motor drivers, encoders, camera, and IMU sensor.

### Board Specifications
- **Dimensions**: TBD (see KiCad layout)
- **Layers**: 2-layer PCB
- **Thickness**: 1.6mm standard FR4
- **Copper Weight**: 1oz (35μm)
- **Finish**: HASL or ENIG

## 🧩 System Components

### Microcontroller
- **ESP32-WROVER Module**
  - Dual-core Xtensa LX6 @ 240MHz
  - 4MB PSRAM for camera buffering
  - WiFi 802.11 b/g/n
  - Bluetooth 4.2 BLE

### Motor Control
- **2× DRV8833 Dual H-Bridge Drivers**
  - Per-channel current rating: 1.5A continuous, 2A peak
  - PWM frequency: 20kHz
  - Sleep/coast control pins
  - Thermal shutdown protection
  - Fault status output

### Sensors

#### Quadrature Encoders (2×)
- **Interface**: ESP32 PCNT peripheral
- **Resolution**: 64 CPR (counts per revolution)
- **Total Resolution**: 4480 counts/rev with 70:1 gearbox
- **Channels**: A, B quadrature signals per encoder
- **Voltage**: 3.3V logic level

#### Camera Module
- **OV5640 5MP Camera**
  - Interface: SCCB (I2C) + parallel data
  - Resolution: 2592×1944 (5MP), configurable
  - Frame Rate: ~15 FPS at 640×480
  - Features: Autofocus, JPEG compression
  - Power: 3.3V digital, 2.8V analog

#### IMU Sensor
- **Adafruit BNO055**
  - 9-DOF sensor fusion (accel + gyro + mag)
  - Interface: I2C (address 0x28 or 0x29)
  - Output: Quaternions, Euler angles, vectors
  - Calibration: Automatic sensor calibration
  - Power: 3.3V

### Power Supply
- **Input**: 7-12V DC (barrel jack or screw terminal)
- **5V Regulator**: Buck converter for motor power
- **3.3V Regulator**: LDO for ESP32 and logic
- **Current Capacity**: 3A total
- **Protection**: Reverse polarity, overcurrent

### Connectors
- **Motor Outputs**: 2× screw terminal blocks (pan & tilt)
- **Encoder Inputs**: 2× 0.1" pin headers (4 pins each)
- **Camera Connector**: FFC/FPC connector (24-pin)
- **IMU Interface**: I2C header or JST connector
- **Programming**: Micro-USB (ESP32 native USB-to-serial)
- **Debug**: UART header for serial monitoring

## 📐 Pin Assignments

### Motor Control
| Motor | IN1 Pin | IN2 Pin | PWM Pin | Sleep Pin |
|---|---|---|---|---|
| Pan | GPIO32  | GPIO33  | GPIO25  | GPIO26 |
| Tilt  | GPIO14  | GPIO27  | GPIO13  | GPIO12 |

### Encoders
| Encoder | Channel A | Channel B | PCNT Unit |
|---|---|---|---|
| Pan | GPIO34 | GPIO35 | PCNT_0 |
| Tilt | GPIO36 | GPIO39 | PCNT_1 |

### Camera (OV5640)
- **SCCB**: SDA=GPIO21, SCL=GPIO22
- **Data**: D0-D7 on GPIO4-5, 18-19, 36-39
- **Control**: VSYNC=GPIO23, HREF=GPIO25, PCLK=GPIO22

### IMU (BNO055)
- **I2C**: SDA=GPIO21, SCL=GPIO22 (shared with camera)
- **INT Pin**: GPIO15 (optional interrupt)
- **RESET**: GPIO2 (optional reset control)

## 🛠️ Design Software

### KiCad (Version 7.0+)
The PCB is designed in KiCad, an open-source electronics design automation suite.

**Opening the Project:**
```bash
# Install KiCad from https://www.kicad.org/
# Open KiCad → File → Open Project
# Select sport_trackr_copy.kicad_pro
```

**Required Symbol Libraries:**
- ESP32 module symbols (custom or contributed)
- DRV8833 motor driver (Texas Instruments)
- Standard passives (resistors, capacitors)
- Connectors (JST, screw terminals, headers)

## 🏭 Manufacturing

### Gerber Files
To generate production files (Gerbers + drill files):
1. Open PCB layout in KiCad PCB Editor
2. File → Plot
3. Select Gerber output format
4. Include layers: F.Cu, B.Cu, F.Mask, B.Mask, F.Silkscreen, B.Silkscreen, Edge.Cuts
5. Generate drill files separately
6. Zip all files for manufacturer

### Recommended Manufacturers
- **JLCPCB** - Low cost, fast turnaround
- **PCBWay** - Good quality, assembly services
- **OSH Park** - USA-based, purple boards
- **ALLPCB** - Economical for prototypes

### Bill of Materials (BOM)
Major components (see full BOM in KiCad):
- 1× ESP32-WROVER module
- 2× DRV8833 motor driver IC (HTSSOP package)
- 1× AMS1117-3.3 LDO voltage regulator
- 1× Buck converter module (5V)
- Passives: resistors, capacitors (0805 SMD)
- Connectors: screw terminals, pin headers, FFC connector

### Assembly Notes
- ESP32 module requires careful hand-soldering or reflow
- DRV8833 ICs have thermal pad - ensure proper grounding
- Test all power rails before connecting peripherals
- Program/test ESP32 before final assembly

## 🧪 Testing & Validation

### Power-On Tests
1. ✅ Check 3.3V rail voltage
2. ✅ Check 5V rail voltage
3. ✅ Verify no short circuits
4. ✅ Test USB programming interface

### Peripheral Tests
1. ✅ Motor driver output (no-load PWM)
2. ✅ Encoder pulse counting
3. ✅ Camera SCCB communication (I2C scan)
4. ✅ IMU I2C communication (device ID read)

### Functional Tests
1. ✅ Motor velocity control
2. ✅ Encoder position feedback
3. ✅ Camera frame capture
4. ✅ IMU orientation data
5. ✅ WiFi connectivity

## 🔧 Troubleshooting

### Common Issues

**Motor not spinning:**
- Check PWM signal with oscilloscope
- Verify motor driver sleep pin is HIGH
- Measure motor supply voltage (should be 5V)
- Check for thermal shutdown on DRV8833

**Encoder not counting:**
- Verify 3.3V supply to encoder
- Check A/B signal integrity (use scope)
- Confirm ESP32 PCNT configuration
- Ensure proper pull-up resistors

**Camera not detected:**
- Verify I2C communication (use I2C scanner)
- Check camera module power (3.3V)
- Confirm FFC cable connection
- Test with known-good camera module

**IMU no response:**
- Check I2C address (0x28 default, 0x29 alternate)
- Verify I2C pull-up resistors (2.2kΩ recommended)
- Ensure proper power supply (3.3V)
- Try software reset via RESET pin

## 📄 Schematic Overview

### Power Distribution
- 7-12V input → 5V buck → Motor drivers, camera analog
- 5V → 3.3V LDO → ESP32, sensors, logic

### Signal Routing
- Motor PWM signals use ESP32 LEDC peripheral
- Encoders connect to ESP32 PCNT hardware counters
- Camera uses ESP32 parallel interface (I2S DMA)
- IMU/Camera share I2C bus (GPIO21/22)

### Protection Features
- Reverse polarity diode on power input
- Bypass capacitors on all power rails (0.1μF + 10μF)
- ESD protection on USB port
- Thermal relief on motor driver ground pads

## 🔄 Revision History

- **v1.0** - Initial design with all core functionality
- Future revisions will be documented here

## 📞 Support

For PCB design questions, manufacturing issues, or electrical modifications, contact the electronics design team member or open an issue in the project repository.

## 📚 Related Documentation

- [Software Documentation](../../src/README.md) - Firmware implementation
- [Hardware Drivers](../../src/hardware/README.md) - Low-level peripheral code
- [Mechanical Integration](../cad/README.md) - Physical mounting and assembly

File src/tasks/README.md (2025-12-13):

# FreeRTOS Task Controllers

High-level task implementations coordinating system behavior, sensor fusion, and user interaction using FreeRTOS multitasking.

## 📂 Files

- **MotorTask.cpp/h** - Multi-mode motor control with FSM-based state management
- **EncoderTask.cpp/h** - High-frequency position/velocity measurement and feedback
- **CameraTask.cpp/h** - Computer vision processing for LED detection and tracking
- **ControllerTask.cpp/h** - System coordinator and global mode management
- **UITask.cpp/h** - Web server, WebSocket telemetry, and command processing
- **IMU_TASK.cpp/h** - Inertial measurement and orientation sensing

## Task Architecture
All tasks inherit from FreeRTOS task base and follow these patterns:
- **Fixed-period execution** using `vTaskDelay()`
- **Queue-based communication** for inter-task messaging
- **Shared data structures** with mutex protection
- **State machine logic** for complex behaviors

### Task Priority Hierarchy
```
Priority 5 (Highest) - EncoderTask (time-critical feedback)
Priority 4           - MotorTask (control loop)
Priority 3           - CameraTask (vision processing)
Priority 3           - ControllerTask (coordination)
Priority 2           - IMU_TASK (sensor reading)
Priority 1 (Lowest)  - UITask (network/telemetry)
```

## MotorTask

### Overview
FSM-based motor controller supporting multiple operating modes with PID control, encoder feedback, and camera-based tracking.
MotorTask

### Operating Modes (States)

1. **IDLE**: Motor disabled, awaiting commands
2. **VELOCITY_MODE**: Open-loop velocity control via PWM
3. **POSITION_MODE**: Closed-loop PID position control
4. **CAMERA_MODE**: Visual servoing using camera error signals
5. **MOTOR_TEST**: Diagnostic mode for testing motor response

### FSM State Transitions
```
        [Command]          [Command]
IDLE ─────────────→ VELOCITY_MODE ←──────────→ POSITION_MODE
  ↑                       ↑                          ↑
  │                       │                          │
  └───────────────────────┴──────────────────────────┘
                    [Stop Command]
                    
                [Camera Active]
        POSITION_MODE ──────────→ CAMERA_MODE
```

### Key Features
- **PID Control**: Separate gains for position and velocity modes
- **Saturation Handling**: Anti-windup with integral clamping
- **Smooth Transitions**: Velocity ramping and position interpolation
- **Stiction Offset**: The motor's high gear ratio leads to a high static friction, especially the tilt motor, which only begins to spin at around 35 effort. To overcome this, we have an offset that is added to the effort
- **Safety Limits**: Software position bounds, only for the tilt motor. The tilt motor can only spin in the range of -10 to 150 degrees

### API
```cpp
class MotorTask: public Task {
public:
    MotorTask(const char* name, DRV883* motor, Shares..., PID* velociypid, PID* positionpid, bool isTiltmotor);
  void update() noexcept { fsm_.run_curstate(); }
  static void set_instance(MotorTask* inst) { instance_ = inst; }

private:
  static uint8_t exec_wait() noexcept;
  static uint8_t exec_velorun() noexcept;
  static uint8_t exec_posrun() noexcept;
  static uint8_t exec_camera_posrun() noexcept;
};
```

### Configuration
```cpp
// PID tuning (in main.cpp)
motorTask->set_pid_gains(
    0.5f,  // Kp - Proportional gain
    0.0f,  // Ki - Integral gain (often zero for position)
    0.1f   // Kd - Derivative gain
);
```

##EncoderTask

### Overview
High-frequency task that continuously reads encoder positions, calculates velocities, and provides feedback to motor controllers.
EncoderTask

### Responsibilities
- Read hardware PCNT counters (no CPU overhead)
- Calculate velocity via position differentiation
- Detect and handle counter overflows
- Publish data to shared memory with mutex protection

### Key Features
- **1kHz sampling rate** (1ms period)
- **Velocity filtering**: Moving average or exponential smoothing
- **Overflow detection**: 16-bit counter wraparound handling
- **Zero-crossing**: Detect direction changes

## CameraTask

### Overview
Computer vision task that captures frames, detects LED targets using HSV thresholding, and computes visual servoing error signals for tracking.
CameraTask

### Processing Pipeline
1. **Frame Capture**: Trigger OV5640 JPEG capture (~60-100ms)
2. **Color Conversion**: RGB → HSV color space
3. **Thresholding**: Isolate LED pixels by hue/saturation/value
4. **Blob Detection**: Find largest contiguous region
5. **Centroid Calculation**: Compute target center (x, y)
6. **Error Computation**: Distance from frame center
7. **Error Publishing**: Send to MotorTask via queue

### Key Features
- **Adaptive Detection**: Auto-adjust thresholds based on ambient light
- **Multi-target Support**: Track multiple LEDs (future)
- **Lost Target Handling**: Timeout and search behavior
- **Frame Buffering**: PSRAM-based double buffering
  
## ControllerTask

### Overview
High-level system coordinator that manages global operating modes, coordinates task interactions, and handles mode transitions.
ControllerTask

### System Modes

1. **TRACKER**: Autonomous camera-based tracking
   - Camera detects LED
   - Error sent to motors
   - PID control active
   
2. **TELEOP**: Manual teleoperation
   - User commands from web UI
   - Direct velocity control
   - No autonomous behavior

3. **MOTOR_TEST**: Diagnostic mode
   - Open-loop motor testing
   - Manual PWM control
   - Encoder monitoring

4. **CALIBRATE**: Homing and setup
   - Find mechanical limits
   - Zero encoder positions
   - Validate hardware

## UITask

### Overview
Web server task providing WiFi connectivity, HTTP file serving, WebSocket telemetry streaming, and remote command processing.
UITask

### Responsibilities
- **WiFi Management**: Connect to network, handle reconnection
- **HTTP Server**: Serve web UI files (HTML/CSS/JS)
- **WebSocket Server**: Bidirectional real-time communication
- **Telemetry Publishing**: Stream sensor data to clients (10 Hz)
- **Command Processing**: Parse and execute user commands

### Key Features
- **Async Web Server**: Non-blocking HTTP/WebSocket using ESPAsyncWebServer
- **JSON Communication**: Structured data format for telemetry and commands
- **Auto-Reconnect**: WiFi watchdog with exponential backoff
- **CORS Support**: Cross-origin resource sharing for development

## IMUTASK

### Overview
An inertial measurement task that reads BNO055 sensor data, provides orientation information, and detects motion events.
IMUTask

### Responsibilities
- Read accelerometer, gyroscope, magnetometer data
- Get fused orientation (Euler angles or quaternions)
- Monitor sensor calibration status
- Detect motion/vibration for stability assessment

### Key Features
- **5 Hz update rate**
- **Automatic calibration**: Monitor and report cal status
- **Temperature compensation**: Built-in BNO055 feature
- **Coordinate transforms**: Convert between sensor and world frames

##Task Timing Analysis

| Task | Period | Exec Time | Stack Size |
|---|---|---|---|
| EncoderTask | 10ms | ~50μs | 2KB |
| MotorTask | 50ms | ~200μs | 2KB |
| CameraTask | 100ms  | ~80ms | 8KB |
| ControllerTask | 100ms  | ~100μs | 4KB |
| IMUTASK | 200ms  | ~500μs | 4KB |
| UITask | 200ms  | ~5ms | 8KB |
## Debugging Tasks

### Stack Overflow Detection
```cpp
void run(void* params) {
    while (1) {
        // Task work...
        
        // Check remaining stack
        UBaseType_t watermark = uxTaskGetStackHighWaterMark(NULL);
        if (watermark < 200) {
            Serial.printf("[%s] Low stack: %d bytes\n", 
                          pcTaskGetName(NULL), watermark);
        }
    }
}
```

### Task State Monitoring
```cpp
// In main loop or debug task
void print_task_stats() {
    char stats[512];
    vTaskList(stats);
    Serial.println("Task Name\tState\tPrio\tStack\tNum");
    Serial.println(stats);
}
```

### Timing Profiling
```cpp
void run(void* params) {
    TickType_t start, end;
    
    while (1) {
        start = xTaskGetTickCount();
        
        // Task execution
        
        end = xTaskGetTickCount();
        uint32_t elapsed = (end - start) * portTICK_PERIOD_MS;
        
        if (elapsed > PERIOD_MS * 0.9) {
            Serial.printf("[%s] Deadline miss: %lums\n", 
                          pcTaskGetName(NULL), elapsed);
        }
    }
}
```

## Related Documentation

- [Hardware Drivers](../hardware/README.md) - Low-level peripheral interfaces
- [FSM Framework](../fsm/README.md) - State machine design pattern
- [Software Architecture](../README.md) - Overall system design
- [Web Interface](../../data/README.md) - UI task implementation details

## Best Practices

1. **Always use `vTaskDelay()` or `vTaskDelayUntil()`** - Never use `delay()` in tasks
2. **Check queue return values** - Handle full/empty conditions gracefully
3. **Use appropriate priorities** - Time-critical tasks get higher priority
4. **Size stacks conservatively** - Monitor high water mark and adjust
5. **Protect shared resources** - Use mutexes for all shared data
6. **Avoid blocking in high-priority tasks** - Defer heavy work to lower priority
7. **Handle task errors** - Don't let exceptions crash the RTOS
8. **Document inter-task dependencies** - Make communication patterns clear

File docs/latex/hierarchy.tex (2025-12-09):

\doxysection{Class Hierarchy}
This inheritance list is sorted roughly, but not completely, alphabetically\+:\begin{DoxyCompactList}
\item \contentsline{section}{Accel\+Data}{\pageref{struct_accel_data}}{}
\item \contentsline{section}{adafruit\+\_\+bno055\+\_\+offsets\+\_\+t}{\pageref{structadafruit__bno055__offsets__t}}{}
\item \contentsline{section}{Adafruit\+\_\+\+BNO055\+::adafruit\+\_\+bno055\+\_\+rev\+\_\+info\+\_\+t}{\pageref{struct_adafruit___b_n_o055_1_1adafruit__bno055__rev__info__t}}{}
\item Adafruit\+\_\+\+Sensor\begin{DoxyCompactList}
\item \contentsline{section}{Adafruit\+\_\+\+BNO055}{\pageref{class_adafruit___b_n_o055}}{}
\end{DoxyCompactList}
\item \contentsline{section}{Camera\+Task}{\pageref{class_camera_task}}{}
\item \contentsline{section}{Controller\+Task}{\pageref{class_controller_task}}{}
\item \contentsline{section}{DRV883}{\pageref{class_d_r_v883}}{}
\item \contentsline{section}{Encoder}{\pageref{class_encoder}}{}
\item \contentsline{section}{Encoder\+Task}{\pageref{class_encoder_task}}{}
\item \contentsline{section}{Euler\+Angles}{\pageref{struct_euler_angles}}{}
\item \contentsline{section}{FSM}{\pageref{class_f_s_m}}{}
\item \contentsline{section}{Gyro\+Data}{\pageref{struct_gyro_data}}{}
\item \contentsline{section}{IMUTask}{\pageref{class_i_m_u_task}}{}
\item \contentsline{section}{Motor\+DRV883}{\pageref{class_motor_d_r_v883}}{}
\item \contentsline{section}{Motor\+Task}{\pageref{class_motor_task}}{}
\item \contentsline{section}{OV5640\+Camera}{\pageref{class_o_v5640_camera}}{}
\item \contentsline{section}{State}{\pageref{class_state}}{}
\item \contentsline{section}{UITask}{\pageref{class_u_i_task}}{}
\end{DoxyCompactList}

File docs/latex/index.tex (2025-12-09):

\chapter{Adafruit BNO055 Orientation Sensor }
\hypertarget{index}{}\label{index}\index{Adafruit BNO055 Orientation Sensor@{Adafruit BNO055 Orientation Sensor}}
\hypertarget{index_intro_sec}{}\doxysection{\texorpdfstring{Introduction}{Introduction}}\label{index_intro_sec}
This is a library for the BNO055 orientation sensor

Designed specifically to work with the Adafruit BNO055 9-\/DOF Breakout.

Pick one up today in the adafruit shop! -\/-\/-\/-\/-\/-\/\texorpdfstring{$>$}{>} \href{https://www.adafruit.com/product/2472}{\texttt{https\+://www.\+adafruit.\+com/product/2472}}

These sensors use I2C to communicate, 2 pins are required to interface.

Adafruit invests time and resources providing this open source code, please support Adafruit andopen-\/source hardware by purchasing products from Adafruit!\hypertarget{index_author}{}\doxysection{\texorpdfstring{Author}{Author}}\label{index_author}
K.\+Townsend (Adafruit Industries)\hypertarget{index_license}{}\doxysection{\texorpdfstring{License}{License}}\label{index_license}
MIT license, all text above must be included in any redistribution

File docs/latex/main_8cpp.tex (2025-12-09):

\doxysection{src/main.cpp File Reference}
\hypertarget{main_8cpp}{}\label{main_8cpp}\index{src/main.cpp@{src/main.cpp}}

Main application entry point for ESP32 camera-\/guided pan-\/tilt tracking system.  

{\ttfamily \#include $<$Arduino.\+h$>$}\newline
{\ttfamily \#include $<$cstdint$>$}\newline
{\ttfamily \#include "{}hardware/\+DRV883.\+h"{}}\newline
{\ttfamily \#include "{}tasks/\+Motor\+Task.\+h"{}}\newline
{\ttfamily \#include "{}hardware/\+Encoder.\+h"{}}\newline
{\ttfamily \#include "{}tasks/\+Encoder\+Task.\+h"{}}\newline
{\ttfamily \#include "{}tasks/\+UITask.\+h"{}}\newline
{\ttfamily \#include "{}tasks/\+IMU\+\_\+\+Task.\+h"{}}\newline
{\ttfamily \#include $<$Wire.\+h$>$}\newline
{\ttfamily \#include "{}hardware/\+Adafruit\+\_\+\+BNO055.\+h"{}}\newline
{\ttfamily \#include "{}tasks/\+Camera\+Task.\+h"{}}\newline
{\ttfamily \#include "{}tasks/\+Controller\+Task.\+h"{}}\newline
{\ttfamily \#include "{}hardware/\+OV5640\+\_\+camera.\+h"{}}\newline
{\ttfamily \#include "{}freertos/\+Free\+RTOS.\+h"{}}\newline
{\ttfamily \#include "{}freertos/task.\+h"{}}\newline
{\ttfamily \#include "{}freertos/queue.\+h"{}}\newline
{\ttfamily \#include "{}taskshare.\+h"{}}\newline
\doxysubsubsection*{Macros}
\begin{DoxyCompactItemize}
\item 
\#define \mbox{\hyperlink{main_8cpp_a4f5313f502282fbcfd79f30302a3c82b}{Pan\+IN1}}~GPIO\+\_\+\+NUM\+\_\+2
\item 
\#define \mbox{\hyperlink{main_8cpp_ad46c6e4ac5145a2506b854c28c625aa3}{Pan\+IN2}}~GPIO\+\_\+\+NUM\+\_\+5
\item 
\#define \mbox{\hyperlink{main_8cpp_a774a219393764de432dda837a163ca48}{n\+SLP\+\_\+\+PIN}}~GPIO\+\_\+\+NUM\+\_\+13
\item 
\#define \mbox{\hyperlink{main_8cpp_a807a9e87c5be79125356eef1028e785d}{Tilt\+ENCODER\+\_\+\+A\+\_\+\+GPIO}}~GPIO\+\_\+\+NUM\+\_\+14
\item 
\#define \mbox{\hyperlink{main_8cpp_ada9b39849b57a988ff22ec9550a1769d}{Tilt\+ENCODER\+\_\+\+B\+\_\+\+GPIO}}~GPIO\+\_\+\+NUM\+\_\+19
\item 
\#define \mbox{\hyperlink{main_8cpp_a1f1ad57f1c6023f908eb9446b759205a}{Tilt\+ENCODER\+\_\+\+UNIT}}~PCNT\+\_\+\+UNIT\+\_\+0
\item 
\#define \mbox{\hyperlink{main_8cpp_a8e5bb8b9c5447a5a1636521c1eee0247}{Tilt\+IN1}}~GPIO\+\_\+\+NUM\+\_\+18
\item 
\#define \mbox{\hyperlink{main_8cpp_ad6a84ed2a08e70da7d9adda71470ead4}{Tilt\+IN2}}~GPIO\+\_\+\+NUM\+\_\+23
\item 
\#define \mbox{\hyperlink{main_8cpp_abdc6a0c3b4366410882e9b2728609e5a}{Pan\+ENCODER\+\_\+\+A\+\_\+\+GPIO}}~GPIO\+\_\+\+NUM\+\_\+3
\item 
\#define \mbox{\hyperlink{main_8cpp_a4d0ee5bdfb147d04624ac2d8aefbff46}{Pan\+ENCODER\+\_\+\+B\+\_\+\+GPIO}}~GPIO\+\_\+\+NUM\+\_\+1
\item 
\#define \mbox{\hyperlink{main_8cpp_a039cf14d1dd6ffcb54227fda70d740a6}{Pan\+ENCODER\+\_\+\+UNIT}}~PCNT\+\_\+\+UNIT\+\_\+1
\end{DoxyCompactItemize}
\doxysubsubsection*{Functions}
\begin{DoxyCompactItemize}
\item 
void \mbox{\hyperlink{main_8cpp_a47703f0cbab9e92ed10160ce53f4f96d}{ui\+\_\+task\+\_\+func}} (void \texorpdfstring{$\ast$}{*}arg)
\item 
void \mbox{\hyperlink{main_8cpp_af5729a7ef453042a1e3635e886a73167}{imu\+\_\+task\+\_\+func}} (void \texorpdfstring{$\ast$}{*}arg)
\begin{DoxyCompactList}\small\item\em Free\+RTOS task entry point for IMU data acquisition. \end{DoxyCompactList}\item 
void \mbox{\hyperlink{main_8cpp_a666b8f7e8309abb257c178d08fdaec1c}{controller\+\_\+task\+\_\+func}} (void \texorpdfstring{$\ast$}{*}arg)
\begin{DoxyCompactList}\small\item\em Free\+RTOS task entry; repeatedly calls update() at configured period. \end{DoxyCompactList}\item 
void \mbox{\hyperlink{main_8cpp_aa4f3a74fdc57aa9bd8666a9a682e75cd}{camera\+\_\+task\+\_\+func}} (void \texorpdfstring{$\ast$}{*}arg)
\begin{DoxyCompactList}\small\item\em Free\+RTOS task entry point for camera vision processing. \end{DoxyCompactList}\item 
void \mbox{\hyperlink{main_8cpp_afc9c2cf42049d569d15d14db75a3e661}{tilt\+\_\+motor\+\_\+task\+\_\+func}} (void \texorpdfstring{$\ast$}{*}arg)
\begin{DoxyCompactList}\small\item\em Free\+RTOS task entry point for tilt motor control. \end{DoxyCompactList}\item 
void \mbox{\hyperlink{main_8cpp_a302862cb5caa69a143d50001e12ef2a4}{pan\+\_\+motor\+\_\+task\+\_\+func}} (void \texorpdfstring{$\ast$}{*}arg)
\begin{DoxyCompactList}\small\item\em Free\+RTOS task entry point for pan motor control. \end{DoxyCompactList}\item 
void \mbox{\hyperlink{main_8cpp_a772e97ad5fae7403b411a5522fed540c}{tilt\+\_\+encoder\+\_\+task\+\_\+func}} (void \texorpdfstring{$\ast$}{*}arg)
\begin{DoxyCompactList}\small\item\em Free\+RTOS task entry point for tilt encoder monitoring. \end{DoxyCompactList}\item 
void \mbox{\hyperlink{main_8cpp_a0189909595ebf63214312f1e6fb9abea}{pan\+\_\+encoder\+\_\+task\+\_\+func}} (void \texorpdfstring{$\ast$}{*}arg)
\begin{DoxyCompactList}\small\item\em Free\+RTOS task entry point for pan encoder monitoring. \end{DoxyCompactList}\item 
void \mbox{\hyperlink{main_8cpp_a4fc01d736fe50cf5b977f755b675f11d}{setup}} ()
\begin{DoxyCompactList}\small\item\em Arduino \doxylink{main_8cpp_a4fc01d736fe50cf5b977f755b675f11d}{setup()} -\/ System initialization and Free\+RTOS task creation. \end{DoxyCompactList}\item 
void \mbox{\hyperlink{main_8cpp_afe461d27b9c48d5921c00d521181f12f}{loop}} ()
\begin{DoxyCompactList}\small\item\em Arduino \doxylink{main_8cpp_afe461d27b9c48d5921c00d521181f12f}{loop()} -\/ Idle function for Free\+RTOS operation. \end{DoxyCompactList}\end{DoxyCompactItemize}
\doxysubsubsection*{Variables}
\begin{DoxyCompactItemize}
\item 
\mbox{\hyperlink{class_o_v5640_camera}{OV5640\+Camera}} \mbox{\hyperlink{main_8cpp_a75f0a8d83ec4ecf50ce67b9df42431e7}{camera}} = \mbox{\hyperlink{class_o_v5640_camera}{OV5640\+Camera}}(760)
\item 
\mbox{\hyperlink{class_d_r_v883}{DRV883}} \mbox{\hyperlink{main_8cpp_a000b34f09d3812c2177cbbc34e41bddc}{panmotor}} (\mbox{\hyperlink{main_8cpp_a4f5313f502282fbcfd79f30302a3c82b}{Pan\+IN1}}, \mbox{\hyperlink{main_8cpp_ad46c6e4ac5145a2506b854c28c625aa3}{Pan\+IN2}}, 0, 1)
\item 
\mbox{\hyperlink{class_encoder}{Encoder}} \mbox{\hyperlink{main_8cpp_a8782c85d1bc81cddd908140fa492fbe6}{panencoder}} (\mbox{\hyperlink{main_8cpp_abdc6a0c3b4366410882e9b2728609e5a}{Pan\+ENCODER\+\_\+\+A\+\_\+\+GPIO}}, \mbox{\hyperlink{main_8cpp_a4d0ee5bdfb147d04624ac2d8aefbff46}{Pan\+ENCODER\+\_\+\+B\+\_\+\+GPIO}}, \mbox{\hyperlink{main_8cpp_a039cf14d1dd6ffcb54227fda70d740a6}{Pan\+ENCODER\+\_\+\+UNIT}})
\item 
\mbox{\hyperlink{class_d_r_v883}{DRV883}} \mbox{\hyperlink{main_8cpp_ae8dcde356db462b2a7c48185714cf52c}{tiltmotor}} (\mbox{\hyperlink{main_8cpp_a8e5bb8b9c5447a5a1636521c1eee0247}{Tilt\+IN1}}, \mbox{\hyperlink{main_8cpp_ad6a84ed2a08e70da7d9adda71470ead4}{Tilt\+IN2}}, 2, 3)
\item 
\mbox{\hyperlink{class_encoder}{Encoder}} \mbox{\hyperlink{main_8cpp_ab54cdca66fa3cc7eb57b1edd9e77a716}{tiltencoder}} (\mbox{\hyperlink{main_8cpp_a807a9e87c5be79125356eef1028e785d}{Tilt\+ENCODER\+\_\+\+A\+\_\+\+GPIO}}, \mbox{\hyperlink{main_8cpp_ada9b39849b57a988ff22ec9550a1769d}{Tilt\+ENCODER\+\_\+\+B\+\_\+\+GPIO}}, \mbox{\hyperlink{main_8cpp_a1f1ad57f1c6023f908eb9446b759205a}{Tilt\+ENCODER\+\_\+\+UNIT}})
\item 
Two\+Wire \mbox{\hyperlink{main_8cpp_aa5098f58d7b46d0b1449973242d4fe60}{I2C}} = Two\+Wire(0)
\item 
\mbox{\hyperlink{class_adafruit___b_n_o055}{Adafruit\+\_\+\+BNO055}} \mbox{\hyperlink{main_8cpp_a52dc7a530bd2ac368f726eac25d55494}{bno055\+\_\+sensor}} = \mbox{\hyperlink{class_adafruit___b_n_o055}{Adafruit\+\_\+\+BNO055}}(1234, 0x28, \&\mbox{\hyperlink{main_8cpp_aa5098f58d7b46d0b1449973242d4fe60}{I2C}})
\item 
Share$<$ int16\+\_\+t $>$ \mbox{\hyperlink{main_8cpp_ae3eba6e3647d2c7fcdc8b9048469268f}{pan\+\_\+err}} \{"{}pan\+\_\+err"{}\}
\item 
Share$<$ int16\+\_\+t $>$ \mbox{\hyperlink{main_8cpp_a1f089d0053c4e4c30975796ecede8618}{tilt\+\_\+err}} \{"{}tilt\+\_\+err"{}\}
\item 
Share$<$ bool $>$ \mbox{\hyperlink{main_8cpp_a875d2c5c4866849a876579d2c92d5c6e}{has\+Led}} \{"{}has\+Led"{}\}
\item 
Share$<$ uint16\+\_\+t $>$ \mbox{\hyperlink{main_8cpp_ad269aac01e7c58c2bfc634fbef929289}{led\+Threshold}} \{"{}led\+Threshold"{}\}
\item 
Share$<$ uint8\+\_\+t $>$ \mbox{\hyperlink{main_8cpp_a721f332798069cf7abda5b39364ba45a}{cam\+\_\+\+Mode}} \{"{}cam\+Mode"{}\}
\item 
Share$<$ uint8\+\_\+t $>$ \mbox{\hyperlink{main_8cpp_a1c51aaca3189ef0686fe5a8dffce1a99}{UI\+\_\+mode}} \{"{}UI\+\_\+mode"{}\}
\item 
Share$<$ bool $>$ \mbox{\hyperlink{main_8cpp_a8a05a0fb1f3d54da915fe436864de249}{dcalibrate}} \{"{}dcalibrate"{}\}
\item 
Share$<$ float $>$ \mbox{\hyperlink{main_8cpp_a5d636c57d472db8f6188090ac3b20f79}{tilt\+\_\+enc\+Position}} \{"{}tiltenc\+\_\+pos"{}\}
\item 
Share$<$ float $>$ \mbox{\hyperlink{main_8cpp_ad6e508aaf5760993011a095c6fe4bb5c}{tilt\+\_\+enc\+Velocity}} \{"{}tiltenc\+\_\+vel"{}\}
\item 
Share$<$ float $>$ \mbox{\hyperlink{main_8cpp_abac84b503e5384bc907d1ebe03b84639}{pan\+\_\+enc\+Position}} \{"{}panenc\+\_\+pos"{}\}
\item 
Share$<$ float $>$ \mbox{\hyperlink{main_8cpp_a37117fd09522ec77568fc16714c6bd45}{pan\+\_\+enc\+Velocity}} \{"{}panenc\+\_\+vel"{}\}
\item 
Share$<$ int8\+\_\+t $>$ \mbox{\hyperlink{main_8cpp_a96b1d304ef59f992b9c7f26d345bd3bd}{tilt\+\_\+vref}} \{"{}tiltvref"{}\}
\item 
Share$<$ int16\+\_\+t $>$ \mbox{\hyperlink{main_8cpp_a2c11930701703706b683072d5f5b7f34}{tilt\+\_\+posref}} \{"{}tiltposref"{}\}
\item 
Share$<$ int8\+\_\+t $>$ \mbox{\hyperlink{main_8cpp_a22f65a631b2d8634743b796fe8177a85}{pan\+\_\+vref}} \{"{}panvref"{}\}
\item 
Share$<$ int16\+\_\+t $>$ \mbox{\hyperlink{main_8cpp_a7ed3ad0733ad4ecedf22eb04235e7505}{pan\+\_\+posref}} \{"{}panposref"{}\}
\item 
Share$<$ uint8\+\_\+t $>$ \mbox{\hyperlink{main_8cpp_a9a053dffceaa3d3bbddb421847244cd4}{tilt\+\_\+\+Cmd}} \{"{}tiltenc\+\_\+cmd"{}\}
\item 
Share$<$ uint8\+\_\+t $>$ \mbox{\hyperlink{main_8cpp_a5256688222b72b10ffdfe995f734004f}{pan\+\_\+\+Cmd}} \{"{}panenc\+\_\+cmd"{}\}
\item 
Share$<$ bool $>$ \mbox{\hyperlink{main_8cpp_a0c7f093b10e321a361eb12f2bbc5092c}{tilt\+\_\+enc\+Zero}} \{"{}tiltenc\+\_\+zero"{}\}
\item 
Share$<$ bool $>$ \mbox{\hyperlink{main_8cpp_ac1a325967c4f5dce4f46a77267befb72}{pan\+\_\+enc\+Zero}} \{"{}panenc\+\_\+zero"{}\}
\item 
Share$<$ int8\+\_\+t $>$ \mbox{\hyperlink{main_8cpp_a14bf215e19290b734fc9afcc52d93fc8}{dpad\+\_\+pan}} \{"{}dpad\+\_\+pan"{}\}
\item 
Share$<$ int8\+\_\+t $>$ \mbox{\hyperlink{main_8cpp_a9afeb6d51496f00818021a457cc17ac6}{dpad\+\_\+tilt}} \{"{}dpad\+\_\+tilt"{}\}
\item 
Share$<$ bool $>$ \mbox{\hyperlink{main_8cpp_a937afed701c3b444b9fbe0355529bbd7}{motortest\+\_\+mode}} \{"{}motortest\+\_\+mode"{}\}
\item 
Share$<$ bool $>$ \mbox{\hyperlink{main_8cpp_ab1874b468c8f4403be5bde3cc31d1c2d}{imu\+\_\+mode}} \{"{}imu\+\_\+mode"{}\}
\item 
Share$<$ \mbox{\hyperlink{struct_euler_angles}{Euler\+Angles}} $>$ \mbox{\hyperlink{main_8cpp_a748452dadde96ed3e8b07ad6b0679d3e}{g\+\_\+euler\+Angles}} \{"{}euler\+\_\+angles"{}\}
\item 
Share$<$ \mbox{\hyperlink{struct_gyro_data}{Gyro\+Data}} $>$ \mbox{\hyperlink{main_8cpp_ab7de3ec279bd1180c7916cc9165d7911}{g\+\_\+gyro\+Data}} \{"{}gyro\+\_\+data"{}\}
\item 
Share$<$ \mbox{\hyperlink{struct_accel_data}{Accel\+Data}} $>$ \mbox{\hyperlink{main_8cpp_af1b1e21003ea927a861341c110222121}{g\+\_\+accel\+Data}} \{"{}accel\+\_\+data"{}\}
\item 
PID \mbox{\hyperlink{main_8cpp_ab5a6f98a1d4dbdc85049552816acaa4e}{tilt\+\_\+velocity\+\_\+pid}}
\item 
PID \mbox{\hyperlink{main_8cpp_a8b499b7c99aaca60891b650d6bd0c809}{tilt\+\_\+position\+\_\+pid}}
\item 
PID \mbox{\hyperlink{main_8cpp_ad114459ce51573253fd6e470f90b2aec}{pan\+\_\+velocity\+\_\+pid}}
\item 
PID \mbox{\hyperlink{main_8cpp_af9936e6055a9cb1a04edf4a69ae076a4}{pan\+\_\+position\+\_\+pid}}
\end{DoxyCompactItemize}

\doxysubsection{Detailed Description}
Main application entry point for ESP32 camera-\/guided pan-\/tilt tracking system. 

This file implements a sophisticated multi-\/axis tracking system combining computer vision, inertial measurement, and PID motor control. The system can automatically track LED targets using camera feedback, provide manual teleoperation via web interface, and stream real-\/time telemetry data including motor positions, IMU orientation, and tracking errors.\hypertarget{main_8cpp_autotoc_md9}{}\doxysubsubsection{\texorpdfstring{System Architecture\+:}{System Architecture\+:}}\label{main_8cpp_autotoc_md9}
The system uses Free\+RTOS multitasking to coordinate seven concurrent tasks\+:

\begin{DoxyEnumerate}
\item {\bfseries{\doxylink{class_motor_task}{Motor\+Task} (Tilt \& Pan)}}\+: Multi-\/mode motor control (velocity, position, camera-\/based)
\item {\bfseries{\doxylink{class_encoder_task}{Encoder\+Task} (Tilt \& Pan)}}\+: High-\/frequency position/velocity measurement via PCNT
\item {\bfseries{\doxylink{class_controller_task}{Controller\+Task}}}\+: Top-\/level \doxylink{class_f_s_m}{FSM} coordinating tracking modes and state transitions
\item {\bfseries{\doxylink{class_camera_task}{Camera\+Task}}}\+: LED detection and visual servoing error computation
\item {\bfseries{\doxylink{class_i_m_u_task}{IMUTask}}}\+: BNO055 9-\/DOF orientation and motion sensing
\item {\bfseries{\doxylink{class_u_i_task}{UITask}}}\+: Web server, Web\+Socket telemetry, and command interface
\end{DoxyEnumerate}\hypertarget{main_8cpp_autotoc_md10}{}\doxysubsubsection{\texorpdfstring{Hardware Components\+:}{Hardware Components\+:}}\label{main_8cpp_autotoc_md10}

\begin{DoxyItemize}
\item ESP32-\/\+WROVER microcontroller (dual-\/core, Wi\+Fi, 8MB PSRAM)
\item 2× DRV8833 dual H-\/bridge motor drivers
\item 2× DC motors with 70\+:1 gearboxes
\item 2× Quadrature encoders (64 CPR)
\item OV5640 camera module (5MP, autofocus)
\item BNO055 9-\/DOF IMU (accelerometer, gyroscope, magnetometer)
\item Pan-\/tilt mechanical platform
\end{DoxyItemize}\hypertarget{main_8cpp_autotoc_md11}{}\doxysubsubsection{\texorpdfstring{Control Modes\+:}{Control Modes\+:}}\label{main_8cpp_autotoc_md11}

\begin{DoxyItemize}
\item {\bfseries{TRACKER}}\+: Automatic LED tracking using camera feedback
\item {\bfseries{TELEOP}}\+: Manual control via web UI D-\/pad
\item {\bfseries{MOTOR\+\_\+\+TEST}}\+: Open-\/loop motor testing for diagnostics
\item {\bfseries{CALIBRATE}}\+: \doxylink{class_encoder}{Encoder} homing and calibration sequence
\end{DoxyItemize}\hypertarget{main_8cpp_autotoc_md12}{}\doxysubsubsection{\texorpdfstring{PID Tuning Guide\+:}{PID Tuning Guide\+:}}\label{main_8cpp_autotoc_md12}
Four independent PID controllers are available for tuning\+:

\begin{DoxyEnumerate}
\item {\bfseries{tilt\+\_\+velocity\+\_\+pid}} -\/ Tilt axis velocity control
\begin{DoxyItemize}
\item Current\+: Kp=0.\+10, Ki=0.\+0, Kd=0.\+0
\item Tuning\+: Increase Kp for faster velocity response, add Ki to eliminate steady-\/state error
\end{DoxyItemize}
\item {\bfseries{tilt\+\_\+position\+\_\+pid}} -\/ Tilt axis position control ~\newline

\begin{DoxyItemize}
\item Current\+: Kp=0.\+080, Ki=0.\+0005, Kd=0.\+0
\item Tuning\+: Increase Kp for stiffer position hold, add Kd to reduce overshoot
\end{DoxyItemize}
\item {\bfseries{pan\+\_\+velocity\+\_\+pid}} -\/ Pan axis velocity control
\begin{DoxyItemize}
\item Current\+: Kp=0.\+10, Ki=0.\+0, Kd=0.\+0
\item Tuning\+: Adjust independently from tilt due to different mechanical characteristics
\end{DoxyItemize}
\item {\bfseries{pan\+\_\+position\+\_\+pid}} -\/ Pan axis position control
\begin{DoxyItemize}
\item Current\+: Kp=0.\+080, Ki=0.\+0005, Kd=0.\+0
\item Tuning\+: May need different gains than tilt due to gravity effects
\end{DoxyItemize}
\end{DoxyEnumerate}

To adjust gains, modify the Init() calls in \doxylink{main_8cpp_a4fc01d736fe50cf5b977f755b675f11d}{setup()}\+: 
\begin{DoxyCode}{0}
\DoxyCodeLine{\mbox{\hyperlink{main_8cpp_ab5a6f98a1d4dbdc85049552816acaa4e}{tilt\_velocity\_pid}}.Init(Kp,\ Ki,\ Kd);}

\end{DoxyCode}
\hypertarget{main_8cpp_autotoc_md13}{}\doxysubsubsection{\texorpdfstring{Network Configuration\+:}{Network Configuration\+:}}\label{main_8cpp_autotoc_md13}

\begin{DoxyItemize}
\item Wi\+Fi SSID/\+Password configured in \doxylink{_u_i_task_8cpp}{UITask.\+cpp}
\item Web interface accessible at\+: \href{http://}{\texttt{http\+://}}$<$\+ESP32\+\_\+\+IP\+\_\+\+ADDRESS$>$
\item Web\+Socket telemetry on same port as HTTP server
\item Serial debug output at 115200 baud
\end{DoxyItemize}\hypertarget{main_8cpp_autotoc_md14}{}\doxysubsubsection{\texorpdfstring{Pin Assignments\+:}{Pin Assignments\+:}}\label{main_8cpp_autotoc_md14}
See hardware configuration section in \doxylink{main_8cpp_a4fc01d736fe50cf5b977f755b675f11d}{setup()} for complete GPIO mapping\+:
\begin{DoxyItemize}
\item Motors\+: GPIO pins for DRV8833 IN1/\+IN2
\item Encoders\+: GPIO pins for Phase A/B quadrature signals
\item Camera\+: SPIO interface to OV5640
\item IMU\+: I2C interface to BNO055
\end{DoxyItemize}

\begin{DoxyAuthor}{Author}
Motor Control Development Team 
\end{DoxyAuthor}
\begin{DoxyDate}{Date}
December 2025 
\end{DoxyDate}
\begin{DoxyVersion}{Version}
2.\+7
\end{DoxyVersion}
\begin{DoxySeeAlso}{See also}
\doxylink{_motor_task_8h}{Motor\+Task.\+h} for motor control implementation 

\doxylink{_camera_task_8h}{Camera\+Task.\+h} for computer vision details 

\doxylink{_controller_task_8h}{Controller\+Task.\+h} for \doxylink{class_f_s_m}{FSM} state descriptions 
\end{DoxySeeAlso}

\label{doc-define-members}
\Hypertarget{main_8cpp_doc-define-members}
\doxysubsection{Macro Definition Documentation}
\Hypertarget{main_8cpp_a774a219393764de432dda837a163ca48}\index{main.cpp@{main.cpp}!nSLP\_PIN@{nSLP\_PIN}}
\index{nSLP\_PIN@{nSLP\_PIN}!main.cpp@{main.cpp}}
\doxysubsubsection{\texorpdfstring{nSLP\_PIN}{nSLP\_PIN}}
{\footnotesize\ttfamily \label{main_8cpp_a774a219393764de432dda837a163ca48} 
\#define n\+SLP\+\_\+\+PIN~GPIO\+\_\+\+NUM\+\_\+13}

\Hypertarget{main_8cpp_abdc6a0c3b4366410882e9b2728609e5a}\index{main.cpp@{main.cpp}!PanENCODER\_A\_GPIO@{PanENCODER\_A\_GPIO}}
\index{PanENCODER\_A\_GPIO@{PanENCODER\_A\_GPIO}!main.cpp@{main.cpp}}
\doxysubsubsection{\texorpdfstring{PanENCODER\_A\_GPIO}{PanENCODER\_A\_GPIO}}
{\footnotesize\ttfamily \label{main_8cpp_abdc6a0c3b4366410882e9b2728609e5a} 
\#define Pan\+ENCODER\+\_\+\+A\+\_\+\+GPIO~GPIO\+\_\+\+NUM\+\_\+3}

\Hypertarget{main_8cpp_a4d0ee5bdfb147d04624ac2d8aefbff46}\index{main.cpp@{main.cpp}!PanENCODER\_B\_GPIO@{PanENCODER\_B\_GPIO}}
\index{PanENCODER\_B\_GPIO@{PanENCODER\_B\_GPIO}!main.cpp@{main.cpp}}
\doxysubsubsection{\texorpdfstring{PanENCODER\_B\_GPIO}{PanENCODER\_B\_GPIO}}
{\footnotesize\ttfamily \label{main_8cpp_a4d0ee5bdfb147d04624ac2d8aefbff46} 
\#define Pan\+ENCODER\+\_\+\+B\+\_\+\+GPIO~GPIO\+\_\+\+NUM\+\_\+1}

\Hypertarget{main_8cpp_a039cf14d1dd6ffcb54227fda70d740a6}\index{main.cpp@{main.cpp}!PanENCODER\_UNIT@{PanENCODER\_UNIT}}
\index{PanENCODER\_UNIT@{PanENCODER\_UNIT}!main.cpp@{main.cpp}}
\doxysubsubsection{\texorpdfstring{PanENCODER\_UNIT}{PanENCODER\_UNIT}}
{\footnotesize\ttfamily \label{main_8cpp_a039cf14d1dd6ffcb54227fda70d740a6} 
\#define Pan\+ENCODER\+\_\+\+UNIT~PCNT\+\_\+\+UNIT\+\_\+1}

\Hypertarget{main_8cpp_a4f5313f502282fbcfd79f30302a3c82b}\index{main.cpp@{main.cpp}!PanIN1@{PanIN1}}
\index{PanIN1@{PanIN1}!main.cpp@{main.cpp}}
\doxysubsubsection{\texorpdfstring{PanIN1}{PanIN1}}
{\footnotesize\ttfamily \label{main_8cpp_a4f5313f502282fbcfd79f30302a3c82b} 
\#define Pan\+IN1~GPIO\+\_\+\+NUM\+\_\+2}

\Hypertarget{main_8cpp_ad46c6e4ac5145a2506b854c28c625aa3}\index{main.cpp@{main.cpp}!PanIN2@{PanIN2}}
\index{PanIN2@{PanIN2}!main.cpp@{main.cpp}}
\doxysubsubsection{\texorpdfstring{PanIN2}{PanIN2}}
{\footnotesize\ttfamily \label{main_8cpp_ad46c6e4ac5145a2506b854c28c625aa3} 
\#define Pan\+IN2~GPIO\+\_\+\+NUM\+\_\+5}

\Hypertarget{main_8cpp_a807a9e87c5be79125356eef1028e785d}\index{main.cpp@{main.cpp}!TiltENCODER\_A\_GPIO@{TiltENCODER\_A\_GPIO}}
\index{TiltENCODER\_A\_GPIO@{TiltENCODER\_A\_GPIO}!main.cpp@{main.cpp}}
\doxysubsubsection{\texorpdfstring{TiltENCODER\_A\_GPIO}{TiltENCODER\_A\_GPIO}}
{\footnotesize\ttfamily \label{main_8cpp_a807a9e87c5be79125356eef1028e785d} 
\#define Tilt\+ENCODER\+\_\+\+A\+\_\+\+GPIO~GPIO\+\_\+\+NUM\+\_\+14}

\Hypertarget{main_8cpp_ada9b39849b57a988ff22ec9550a1769d}\index{main.cpp@{main.cpp}!TiltENCODER\_B\_GPIO@{TiltENCODER\_B\_GPIO}}
\index{TiltENCODER\_B\_GPIO@{TiltENCODER\_B\_GPIO}!main.cpp@{main.cpp}}
\doxysubsubsection{\texorpdfstring{TiltENCODER\_B\_GPIO}{TiltENCODER\_B\_GPIO}}
{\footnotesize\ttfamily \label{main_8cpp_ada9b39849b57a988ff22ec9550a1769d} 
\#define Tilt\+ENCODER\+\_\+\+B\+\_\+\+GPIO~GPIO\+\_\+\+NUM\+\_\+19}

\Hypertarget{main_8cpp_a1f1ad57f1c6023f908eb9446b759205a}\index{main.cpp@{main.cpp}!TiltENCODER\_UNIT@{TiltENCODER\_UNIT}}
\index{TiltENCODER\_UNIT@{TiltENCODER\_UNIT}!main.cpp@{main.cpp}}
\doxysubsubsection{\texorpdfstring{TiltENCODER\_UNIT}{TiltENCODER\_UNIT}}
{\footnotesize\ttfamily \label{main_8cpp_a1f1ad57f1c6023f908eb9446b759205a} 
\#define Tilt\+ENCODER\+\_\+\+UNIT~PCNT\+\_\+\+UNIT\+\_\+0}

\Hypertarget{main_8cpp_a8e5bb8b9c5447a5a1636521c1eee0247}\index{main.cpp@{main.cpp}!TiltIN1@{TiltIN1}}
\index{TiltIN1@{TiltIN1}!main.cpp@{main.cpp}}
\doxysubsubsection{\texorpdfstring{TiltIN1}{TiltIN1}}
{\footnotesize\ttfamily \label{main_8cpp_a8e5bb8b9c5447a5a1636521c1eee0247} 
\#define Tilt\+IN1~GPIO\+\_\+\+NUM\+\_\+18}

\Hypertarget{main_8cpp_ad6a84ed2a08e70da7d9adda71470ead4}\index{main.cpp@{main.cpp}!TiltIN2@{TiltIN2}}
\index{TiltIN2@{TiltIN2}!main.cpp@{main.cpp}}
\doxysubsubsection{\texorpdfstring{TiltIN2}{TiltIN2}}
{\footnotesize\ttfamily \label{main_8cpp_ad6a84ed2a08e70da7d9adda71470ead4} 
\#define Tilt\+IN2~GPIO\+\_\+\+NUM\+\_\+23}

\label{doc-func-members}
\Hypertarget{main_8cpp_doc-func-members}
\doxysubsection{Function Documentation}
\Hypertarget{main_8cpp_aa4f3a74fdc57aa9bd8666a9a682e75cd}\index{main.cpp@{main.cpp}!camera\_task\_func@{camera\_task\_func}}
\index{camera\_task\_func@{camera\_task\_func}!main.cpp@{main.cpp}}
\doxysubsubsection{\texorpdfstring{camera\_task\_func()}{camera\_task\_func()}}
{\footnotesize\ttfamily \label{main_8cpp_aa4f3a74fdc57aa9bd8666a9a682e75cd} 
void camera\+\_\+task\+\_\+func (\begin{DoxyParamCaption}\item[{void \texorpdfstring{$\ast$}{*}}]{arg}{}\end{DoxyParamCaption})}

Free\+RTOS task entry point for camera vision processing. 

C-\/style function required by x\+Task\+Create(). Creates an infinite loop that periodically calls the camera task\textquotesingle{}s update() method to execute the \doxylink{class_f_s_m}{FSM}.

Task Loop\+:
\begin{DoxyEnumerate}
\item Call update() to execute current \doxylink{class_f_s_m}{FSM} state
\item Delay for 10ms (100Hz maximum frame rate)
\item Repeat indefinitely
\end{DoxyEnumerate}

\begin{DoxyParams}{Parameters}
{\em arg} & Pointer to \doxylink{class_camera_task}{Camera\+Task} object (cast from void\texorpdfstring{$\ast$}{*})\\
\hline
\end{DoxyParams}
\begin{DoxyNote}{Note}
Fixed 10ms delay provides \texorpdfstring{$\sim$}{\string~}100\+Hz maximum frame rate 

Actual frame rate depends on camera capture time and processing 

Task never exits -\/ runs for lifetime of system 
\end{DoxyNote}
\Hypertarget{main_8cpp_a666b8f7e8309abb257c178d08fdaec1c}\index{main.cpp@{main.cpp}!controller\_task\_func@{controller\_task\_func}}
\index{controller\_task\_func@{controller\_task\_func}!main.cpp@{main.cpp}}
\doxysubsubsection{\texorpdfstring{controller\_task\_func()}{controller\_task\_func()}}
{\footnotesize\ttfamily \label{main_8cpp_a666b8f7e8309abb257c178d08fdaec1c} 
void controller\+\_\+task\+\_\+func (\begin{DoxyParamCaption}\item[{void \texorpdfstring{$\ast$}{*}}]{arg}{}\end{DoxyParamCaption})}

Free\+RTOS task entry; repeatedly calls update() at configured period. 

\Hypertarget{main_8cpp_af5729a7ef453042a1e3635e886a73167}\index{main.cpp@{main.cpp}!imu\_task\_func@{imu\_task\_func}}
\index{imu\_task\_func@{imu\_task\_func}!main.cpp@{main.cpp}}
\doxysubsubsection{\texorpdfstring{imu\_task\_func()}{imu\_task\_func()}}
{\footnotesize\ttfamily \label{main_8cpp_af5729a7ef453042a1e3635e886a73167} 
void imu\+\_\+task\+\_\+func (\begin{DoxyParamCaption}\item[{void \texorpdfstring{$\ast$}{*}}]{pv\+Parameters}{}\end{DoxyParamCaption})}

Free\+RTOS task entry point for IMU data acquisition. 

C-\/style function required by x\+Task\+Create(). Creates an infinite loop that periodically calls the IMU task\textquotesingle{}s update() method to execute the \doxylink{class_f_s_m}{FSM}.

Task Loop\+:
\begin{DoxyEnumerate}
\item Set static instance pointer for callback access
\item Call update() to execute current \doxylink{class_f_s_m}{FSM} state
\item Delay for configured sample interval
\item Repeat indefinitely
\end{DoxyEnumerate}

\begin{DoxyParams}{Parameters}
{\em pv\+Parameters} & Pointer to \doxylink{class_i_m_u_task}{IMUTask} object (cast from void\texorpdfstring{$\ast$}{*})\\
\hline
\end{DoxyParams}
\begin{DoxyNote}{Note}
Delay duration matches update\+Ms\+\_\+ from \doxylink{class_i_m_u_task}{IMUTask} configuration 

Task never exits -\/ runs for lifetime of system 
\end{DoxyNote}
\Hypertarget{main_8cpp_afe461d27b9c48d5921c00d521181f12f}\index{main.cpp@{main.cpp}!loop@{loop}}
\index{loop@{loop}!main.cpp@{main.cpp}}
\doxysubsubsection{\texorpdfstring{loop()}{loop()}}
{\footnotesize\ttfamily \label{main_8cpp_afe461d27b9c48d5921c00d521181f12f} 
void loop (\begin{DoxyParamCaption}{}{}\end{DoxyParamCaption})}

Arduino \doxylink{main_8cpp_afe461d27b9c48d5921c00d521181f12f}{loop()} -\/ Idle function for Free\+RTOS operation. 

In a Free\+RTOS-\/based system, the Arduino \doxylink{main_8cpp_afe461d27b9c48d5921c00d521181f12f}{loop()} function is not used for main program logic. All application code runs in Free\+RTOS tasks created in \doxylink{main_8cpp_a4fc01d736fe50cf5b977f755b675f11d}{setup()}. The \doxylink{main_8cpp_afe461d27b9c48d5921c00d521181f12f}{loop()} function simply delays indefinitely to prevent watchdog timer resets.

Task Execution\+:
\begin{DoxyItemize}
\item All seven tasks run concurrently under Free\+RTOS scheduler
\item Task priorities determine execution order when multiple tasks ready
\item v\+Task\+Delay() in each task yields CPU to other tasks
\item Free\+RTOS idle task runs when no other tasks ready (manages power)
\end{DoxyItemize}

\begin{DoxyNote}{Note}
This function runs on ESP32 core 1 (setup/loop core) 

Free\+RTOS scheduler manages all task execution timing 

Infinite delay prevents watchdog timer from triggering 

To modify system behavior, edit task code, not \doxylink{main_8cpp_afe461d27b9c48d5921c00d521181f12f}{loop()} 
\end{DoxyNote}
\Hypertarget{main_8cpp_a0189909595ebf63214312f1e6fb9abea}\index{main.cpp@{main.cpp}!pan\_encoder\_task\_func@{pan\_encoder\_task\_func}}
\index{pan\_encoder\_task\_func@{pan\_encoder\_task\_func}!main.cpp@{main.cpp}}
\doxysubsubsection{\texorpdfstring{pan\_encoder\_task\_func()}{pan\_encoder\_task\_func()}}
{\footnotesize\ttfamily \label{main_8cpp_a0189909595ebf63214312f1e6fb9abea} 
void pan\+\_\+encoder\+\_\+task\+\_\+func (\begin{DoxyParamCaption}\item[{void \texorpdfstring{$\ast$}{*}}]{arg}{}\end{DoxyParamCaption})}

Free\+RTOS task entry point for pan encoder monitoring. 

High-\/frequency task for pan axis encoder position and velocity measurement. Operates independently from tilt encoder to provide concurrent feedback for both axes without static instance conflicts.

Task Configuration\+:
\begin{DoxyItemize}
\item Update rate\+: 10ms (100Hz)
\item Priority\+: Typically higher than motor tasks for accurate feedback
\item Stack size\+: Configured in task creation
\end{DoxyItemize}

\begin{DoxyParams}{Parameters}
{\em arg} & Pointer to pan \doxylink{class_encoder_task}{Encoder\+Task} object (cast from void\texorpdfstring{$\ast$}{*})\\
\hline
\end{DoxyParams}
\begin{DoxyNote}{Note}
Matches tilt encoder update rate for consistent control behavior 

Separate task function prevents static instance pointer conflicts 
\end{DoxyNote}
\Hypertarget{main_8cpp_a302862cb5caa69a143d50001e12ef2a4}\index{main.cpp@{main.cpp}!pan\_motor\_task\_func@{pan\_motor\_task\_func}}
\index{pan\_motor\_task\_func@{pan\_motor\_task\_func}!main.cpp@{main.cpp}}
\doxysubsubsection{\texorpdfstring{pan\_motor\_task\_func()}{pan\_motor\_task\_func()}}
{\footnotesize\ttfamily \label{main_8cpp_a302862cb5caa69a143d50001e12ef2a4} 
void pan\+\_\+motor\+\_\+task\+\_\+func (\begin{DoxyParamCaption}\item[{void \texorpdfstring{$\ast$}{*}}]{arg}{}\end{DoxyParamCaption})}

Free\+RTOS task entry point for pan motor control. 

Dedicated task function for pan axis motor control, independent from tilt axis. Maintains separate static instance context to prevent conflicts during concurrent execution of both motor control tasks.

Task Configuration\+:
\begin{DoxyItemize}
\item Update rate\+: 50ms (20Hz)
\item Priority\+: Set during x\+Task\+Create() call
\item Stack size\+: Configured in task creation
\end{DoxyItemize}

\begin{DoxyParams}{Parameters}
{\em arg} & Pointer to pan \doxylink{class_motor_task}{Motor\+Task} object (cast from void\texorpdfstring{$\ast$}{*})\\
\hline
\end{DoxyParams}
\begin{DoxyNote}{Note}
Must be separate from tilt\+\_\+motor\+\_\+task\+\_\+func due to static instance pattern 

Both motor tasks run concurrently without interference 
\end{DoxyNote}
\Hypertarget{main_8cpp_a4fc01d736fe50cf5b977f755b675f11d}\index{main.cpp@{main.cpp}!setup@{setup}}
\index{setup@{setup}!main.cpp@{main.cpp}}
\doxysubsubsection{\texorpdfstring{setup()}{setup()}}
{\footnotesize\ttfamily \label{main_8cpp_a4fc01d736fe50cf5b977f755b675f11d} 
void setup (\begin{DoxyParamCaption}{}{}\end{DoxyParamCaption})}

Arduino \doxylink{main_8cpp_a4fc01d736fe50cf5b977f755b675f11d}{setup()} -\/ System initialization and Free\+RTOS task creation. 

This function performs complete system initialization including hardware configuration, communication interface setup, PID controller tuning, and Free\+RTOS task creation. All initialization must complete before tasks begin execution.

Initialization Sequence\+:
\begin{DoxyEnumerate}
\item Initialize all Share$<$\+T$>$ objects to safe default values
\item Configure serial communication (115200 baud)
\item Connect telemetry queues between tasks
\item Initialize I2C bus for IMU communication
\item Initialize BNO055 IMU sensor and load calibration
\item Initialize OV5640 camera module
\item Enable motor drivers (n\+SLP pin HIGH)
\item Configure PID controller gains for all four controllers
\item Initialize Wi\+Fi Access Point and web server
\item Create seven Free\+RTOS tasks with appropriate priorities
\end{DoxyEnumerate}

Task Priority Scheme\+:
\begin{DoxyItemize}
\item Priority 5\+: \doxylink{class_encoder}{Encoder} tasks (highest -\/ critical for control feedback)
\item Priority 4\+: Camera task (high -\/ visual servoing feedback)
\item Priority 3\+: Controller task (medium-\/high -\/ coordination)
\item Priority 2\+: Motor tasks (medium -\/ actuation)
\item Priority 1\+: UI task (low -\/ telemetry and commands)
\item Priority 0\+: IMU task (lowest -\/ supplementary data)
\end{DoxyItemize}

Hardware Configuration\+:
\begin{DoxyItemize}
\item I2C Bus\+: GPIO21 (SDA), GPIO22 (SCL) for IMU
\item Wi\+Fi\+: Access Point mode "{}\+ESP32-\/\+Motor\+Control"{} / "{}motor123"{}
\item Motor Enable\+: GPIO13 (n\+SLP\+\_\+\+PIN) set HIGH
\item Serial\+: 115200 baud for debug output
\end{DoxyItemize}

\begin{DoxyNote}{Note}
GPIO1 used by pan encoder (no USB Serial transmission) 

Camera/\+IMU failures logged but don\textquotesingle{}t halt system startup 

All tasks start immediately after creation 

\doxylink{main_8cpp_a4fc01d736fe50cf5b977f755b675f11d}{setup()} runs once on ESP32 core 1 before scheduler starts 
\end{DoxyNote}
\Hypertarget{main_8cpp_a772e97ad5fae7403b411a5522fed540c}\index{main.cpp@{main.cpp}!tilt\_encoder\_task\_func@{tilt\_encoder\_task\_func}}
\index{tilt\_encoder\_task\_func@{tilt\_encoder\_task\_func}!main.cpp@{main.cpp}}
\doxysubsubsection{\texorpdfstring{tilt\_encoder\_task\_func()}{tilt\_encoder\_task\_func()}}
{\footnotesize\ttfamily \label{main_8cpp_a772e97ad5fae7403b411a5522fed540c} 
void tilt\+\_\+encoder\+\_\+task\+\_\+func (\begin{DoxyParamCaption}\item[{void \texorpdfstring{$\ast$}{*}}]{arg}{}\end{DoxyParamCaption})}

Free\+RTOS task entry point for tilt encoder monitoring. 

High-\/frequency task for tilt axis encoder position and velocity measurement. Runs at 100Hz to minimize control loop latency and ensure accurate velocity calculation via the \doxylink{class_encoder}{Encoder}\textquotesingle{}s sliding window algorithm.

Task Configuration\+:
\begin{DoxyItemize}
\item Update rate\+: 10ms (100Hz)
\item Priority\+: Typically higher than motor tasks for accurate feedback
\item Stack size\+: Configured in task creation
\end{DoxyItemize}

\begin{DoxyParams}{Parameters}
{\em arg} & Pointer to tilt \doxylink{class_encoder_task}{Encoder\+Task} object (cast from void\texorpdfstring{$\ast$}{*})\\
\hline
\end{DoxyParams}
\begin{DoxyNote}{Note}
Fast update rate critical for control loop performance 

Separate from pan encoder to avoid instance conflicts 
\end{DoxyNote}
\Hypertarget{main_8cpp_afc9c2cf42049d569d15d14db75a3e661}\index{main.cpp@{main.cpp}!tilt\_motor\_task\_func@{tilt\_motor\_task\_func}}
\index{tilt\_motor\_task\_func@{tilt\_motor\_task\_func}!main.cpp@{main.cpp}}
\doxysubsubsection{\texorpdfstring{tilt\_motor\_task\_func()}{tilt\_motor\_task\_func()}}
{\footnotesize\ttfamily \label{main_8cpp_afc9c2cf42049d569d15d14db75a3e661} 
void tilt\+\_\+motor\+\_\+task\+\_\+func (\begin{DoxyParamCaption}\item[{void \texorpdfstring{$\ast$}{*}}]{arg}{}\end{DoxyParamCaption})}

Free\+RTOS task entry point for tilt motor control. 

Dedicated task function for tilt axis motor control to avoid static instance conflicts between pan and tilt \doxylink{class_motor_task}{Motor\+Task} objects. Sets the static instance pointer before each update to ensure correct object context.

Task Configuration\+:
\begin{DoxyItemize}
\item Update rate\+: 50ms (20Hz)
\item Priority\+: Set during x\+Task\+Create() call
\item Stack size\+: Configured in task creation
\end{DoxyItemize}

\begin{DoxyParams}{Parameters}
{\em arg} & Pointer to tilt \doxylink{class_motor_task}{Motor\+Task} object (cast from void\texorpdfstring{$\ast$}{*})\\
\hline
\end{DoxyParams}
\begin{DoxyNote}{Note}
Separate task functions required because \doxylink{class_motor_task}{Motor\+Task} uses static instance pattern 

Instance pointer set before each update() call for correct \doxylink{class_f_s_m}{FSM} execution 
\end{DoxyNote}
\Hypertarget{main_8cpp_a47703f0cbab9e92ed10160ce53f4f96d}\index{main.cpp@{main.cpp}!ui\_task\_func@{ui\_task\_func}}
\index{ui\_task\_func@{ui\_task\_func}!main.cpp@{main.cpp}}
\doxysubsubsection{\texorpdfstring{ui\_task\_func()}{ui\_task\_func()}}
{\footnotesize\ttfamily \label{main_8cpp_a47703f0cbab9e92ed10160ce53f4f96d} 
void ui\+\_\+task\+\_\+func (\begin{DoxyParamCaption}\item[{void \texorpdfstring{$\ast$}{*}}]{arg}{}\end{DoxyParamCaption})}

\label{doc-var-members}
\Hypertarget{main_8cpp_doc-var-members}
\doxysubsection{Variable Documentation}
\Hypertarget{main_8cpp_a52dc7a530bd2ac368f726eac25d55494}\index{main.cpp@{main.cpp}!bno055\_sensor@{bno055\_sensor}}
\index{bno055\_sensor@{bno055\_sensor}!main.cpp@{main.cpp}}
\doxysubsubsection{\texorpdfstring{bno055\_sensor}{bno055\_sensor}}
{\footnotesize\ttfamily \label{main_8cpp_a52dc7a530bd2ac368f726eac25d55494} 
\mbox{\hyperlink{class_i_m_u_task}{IMUTask}} imu\+Task \& bno055\+\_\+sensor = \mbox{\hyperlink{class_adafruit___b_n_o055}{Adafruit\+\_\+\+BNO055}}(1234, 0x28, \&\mbox{\hyperlink{main_8cpp_aa5098f58d7b46d0b1449973242d4fe60}{I2C}})}

\Hypertarget{main_8cpp_a721f332798069cf7abda5b39364ba45a}\index{main.cpp@{main.cpp}!cam\_Mode@{cam\_Mode}}
\index{cam\_Mode@{cam\_Mode}!main.cpp@{main.cpp}}
\doxysubsubsection{\texorpdfstring{cam\_Mode}{cam\_Mode}}
{\footnotesize\ttfamily \label{main_8cpp_a721f332798069cf7abda5b39364ba45a} 
Share$<$uint8\+\_\+t$>$ cam\+\_\+\+Mode \{"{}cam\+Mode"{}\}}

\Hypertarget{main_8cpp_a75f0a8d83ec4ecf50ce67b9df42431e7}\index{main.cpp@{main.cpp}!camera@{camera}}
\index{camera@{camera}!main.cpp@{main.cpp}}
\doxysubsubsection{\texorpdfstring{camera}{camera}}
{\footnotesize\ttfamily \label{main_8cpp_a75f0a8d83ec4ecf50ce67b9df42431e7} 
\mbox{\hyperlink{class_camera_task}{Camera\+Task}} camera\+Task \& camera = \mbox{\hyperlink{class_o_v5640_camera}{OV5640\+Camera}}(760)}

\Hypertarget{main_8cpp_a8a05a0fb1f3d54da915fe436864de249}\index{main.cpp@{main.cpp}!dcalibrate@{dcalibrate}}
\index{dcalibrate@{dcalibrate}!main.cpp@{main.cpp}}
\doxysubsubsection{\texorpdfstring{dcalibrate}{dcalibrate}}
{\footnotesize\ttfamily \label{main_8cpp_a8a05a0fb1f3d54da915fe436864de249} 
Share$<$bool$>$ dcalibrate \{"{}dcalibrate"{}\}}

\Hypertarget{main_8cpp_a14bf215e19290b734fc9afcc52d93fc8}\index{main.cpp@{main.cpp}!dpad\_pan@{dpad\_pan}}
\index{dpad\_pan@{dpad\_pan}!main.cpp@{main.cpp}}
\doxysubsubsection{\texorpdfstring{dpad\_pan}{dpad\_pan}}
{\footnotesize\ttfamily \label{main_8cpp_a14bf215e19290b734fc9afcc52d93fc8} 
Share$<$int8\+\_\+t$>$ dpad\+\_\+pan \{"{}dpad\+\_\+pan"{}\}}

\Hypertarget{main_8cpp_a9afeb6d51496f00818021a457cc17ac6}\index{main.cpp@{main.cpp}!dpad\_tilt@{dpad\_tilt}}
\index{dpad\_tilt@{dpad\_tilt}!main.cpp@{main.cpp}}
\doxysubsubsection{\texorpdfstring{dpad\_tilt}{dpad\_tilt}}
{\footnotesize\ttfamily \label{main_8cpp_a9afeb6d51496f00818021a457cc17ac6} 
Share$<$int8\+\_\+t$>$ dpad\+\_\+tilt \{"{}dpad\+\_\+tilt"{}\}}

\Hypertarget{main_8cpp_af1b1e21003ea927a861341c110222121}\index{main.cpp@{main.cpp}!g\_accelData@{g\_accelData}}
\index{g\_accelData@{g\_accelData}!main.cpp@{main.cpp}}
\doxysubsubsection{\texorpdfstring{g\_accelData}{g\_accelData}}
{\footnotesize\ttfamily \label{main_8cpp_af1b1e21003ea927a861341c110222121} 
Share$<$\mbox{\hyperlink{struct_accel_data}{Accel\+Data}}$>$ g\+\_\+accel\+Data \{"{}accel\+\_\+data"{}\}}

\Hypertarget{main_8cpp_a748452dadde96ed3e8b07ad6b0679d3e}\index{main.cpp@{main.cpp}!g\_eulerAngles@{g\_eulerAngles}}
\index{g\_eulerAngles@{g\_eulerAngles}!main.cpp@{main.cpp}}
\doxysubsubsection{\texorpdfstring{g\_eulerAngles}{g\_eulerAngles}}
{\footnotesize\ttfamily \label{main_8cpp_a748452dadde96ed3e8b07ad6b0679d3e} 
Share$<$\mbox{\hyperlink{struct_euler_angles}{Euler\+Angles}}$>$ g\+\_\+euler\+Angles \{"{}euler\+\_\+angles"{}\}}

\Hypertarget{main_8cpp_ab7de3ec279bd1180c7916cc9165d7911}\index{main.cpp@{main.cpp}!g\_gyroData@{g\_gyroData}}
\index{g\_gyroData@{g\_gyroData}!main.cpp@{main.cpp}}
\doxysubsubsection{\texorpdfstring{g\_gyroData}{g\_gyroData}}
{\footnotesize\ttfamily \label{main_8cpp_ab7de3ec279bd1180c7916cc9165d7911} 
Share$<$\mbox{\hyperlink{struct_gyro_data}{Gyro\+Data}}$>$ g\+\_\+gyro\+Data \{"{}gyro\+\_\+data"{}\}}

\Hypertarget{main_8cpp_a875d2c5c4866849a876579d2c92d5c6e}\index{main.cpp@{main.cpp}!hasLed@{hasLed}}
\index{hasLed@{hasLed}!main.cpp@{main.cpp}}
\doxysubsubsection{\texorpdfstring{hasLed}{hasLed}}
{\footnotesize\ttfamily \label{main_8cpp_a875d2c5c4866849a876579d2c92d5c6e} 
Share$<$bool$>$ has\+Led \{"{}has\+Led"{}\}}

\Hypertarget{main_8cpp_aa5098f58d7b46d0b1449973242d4fe60}\index{main.cpp@{main.cpp}!I2C@{I2C}}
\index{I2C@{I2C}!main.cpp@{main.cpp}}
\doxysubsubsection{\texorpdfstring{I2C}{I2C}}
{\footnotesize\ttfamily \label{main_8cpp_aa5098f58d7b46d0b1449973242d4fe60} 
Two\+Wire I2C = Two\+Wire(0)}

\Hypertarget{main_8cpp_ab1874b468c8f4403be5bde3cc31d1c2d}\index{main.cpp@{main.cpp}!imu\_mode@{imu\_mode}}
\index{imu\_mode@{imu\_mode}!main.cpp@{main.cpp}}
\doxysubsubsection{\texorpdfstring{imu\_mode}{imu\_mode}}
{\footnotesize\ttfamily \label{main_8cpp_ab1874b468c8f4403be5bde3cc31d1c2d} 
Share$<$bool$>$ imu\+\_\+mode \{"{}imu\+\_\+mode"{}\}}

\Hypertarget{main_8cpp_ad269aac01e7c58c2bfc634fbef929289}\index{main.cpp@{main.cpp}!ledThreshold@{ledThreshold}}
\index{ledThreshold@{ledThreshold}!main.cpp@{main.cpp}}
\doxysubsubsection{\texorpdfstring{ledThreshold}{ledThreshold}}
{\footnotesize\ttfamily \label{main_8cpp_ad269aac01e7c58c2bfc634fbef929289} 
Share$<$uint16\+\_\+t$>$ led\+Threshold \{"{}led\+Threshold"{}\}}

\Hypertarget{main_8cpp_a937afed701c3b444b9fbe0355529bbd7}\index{main.cpp@{main.cpp}!motortest\_mode@{motortest\_mode}}
\index{motortest\_mode@{motortest\_mode}!main.cpp@{main.cpp}}
\doxysubsubsection{\texorpdfstring{motortest\_mode}{motortest\_mode}}
{\footnotesize\ttfamily \label{main_8cpp_a937afed701c3b444b9fbe0355529bbd7} 
Share$<$bool$>$ motortest\+\_\+mode \{"{}motortest\+\_\+mode"{}\}}

\Hypertarget{main_8cpp_a5256688222b72b10ffdfe995f734004f}\index{main.cpp@{main.cpp}!pan\_Cmd@{pan\_Cmd}}
\index{pan\_Cmd@{pan\_Cmd}!main.cpp@{main.cpp}}
\doxysubsubsection{\texorpdfstring{pan\_Cmd}{pan\_Cmd}}
{\footnotesize\ttfamily \label{main_8cpp_a5256688222b72b10ffdfe995f734004f} 
Share$<$uint8\+\_\+t$>$ pan\+\_\+\+Cmd \{"{}panenc\+\_\+cmd"{}\}}

\Hypertarget{main_8cpp_abac84b503e5384bc907d1ebe03b84639}\index{main.cpp@{main.cpp}!pan\_encPosition@{pan\_encPosition}}
\index{pan\_encPosition@{pan\_encPosition}!main.cpp@{main.cpp}}
\doxysubsubsection{\texorpdfstring{pan\_encPosition}{pan\_encPosition}}
{\footnotesize\ttfamily \label{main_8cpp_abac84b503e5384bc907d1ebe03b84639} 
Share$<$float$>$ pan\+\_\+enc\+Position \{"{}panenc\+\_\+pos"{}\}}

\Hypertarget{main_8cpp_a37117fd09522ec77568fc16714c6bd45}\index{main.cpp@{main.cpp}!pan\_encVelocity@{pan\_encVelocity}}
\index{pan\_encVelocity@{pan\_encVelocity}!main.cpp@{main.cpp}}
\doxysubsubsection{\texorpdfstring{pan\_encVelocity}{pan\_encVelocity}}
{\footnotesize\ttfamily \label{main_8cpp_a37117fd09522ec77568fc16714c6bd45} 
Share$<$float$>$ pan\+\_\+enc\+Velocity \{"{}panenc\+\_\+vel"{}\}}

\Hypertarget{main_8cpp_ac1a325967c4f5dce4f46a77267befb72}\index{main.cpp@{main.cpp}!pan\_encZero@{pan\_encZero}}
\index{pan\_encZero@{pan\_encZero}!main.cpp@{main.cpp}}
\doxysubsubsection{\texorpdfstring{pan\_encZero}{pan\_encZero}}
{\footnotesize\ttfamily \label{main_8cpp_ac1a325967c4f5dce4f46a77267befb72} 
Share$<$bool$>$ pan\+\_\+enc\+Zero \{"{}panenc\+\_\+zero"{}\}}

\Hypertarget{main_8cpp_ae3eba6e3647d2c7fcdc8b9048469268f}\index{main.cpp@{main.cpp}!pan\_err@{pan\_err}}
\index{pan\_err@{pan\_err}!main.cpp@{main.cpp}}
\doxysubsubsection{\texorpdfstring{pan\_err}{pan\_err}}
{\footnotesize\ttfamily \label{main_8cpp_ae3eba6e3647d2c7fcdc8b9048469268f} 
\mbox{\hyperlink{class_controller_task}{Controller\+Task}} controller\+Task \& pan\+\_\+err \{"{}pan\+\_\+err"{}\}}

\Hypertarget{main_8cpp_af9936e6055a9cb1a04edf4a69ae076a4}\index{main.cpp@{main.cpp}!pan\_position\_pid@{pan\_position\_pid}}
\index{pan\_position\_pid@{pan\_position\_pid}!main.cpp@{main.cpp}}
\doxysubsubsection{\texorpdfstring{pan\_position\_pid}{pan\_position\_pid}}
{\footnotesize\ttfamily \label{main_8cpp_af9936e6055a9cb1a04edf4a69ae076a4} 
PID pan\+\_\+position\+\_\+pid}

\Hypertarget{main_8cpp_a7ed3ad0733ad4ecedf22eb04235e7505}\index{main.cpp@{main.cpp}!pan\_posref@{pan\_posref}}
\index{pan\_posref@{pan\_posref}!main.cpp@{main.cpp}}
\doxysubsubsection{\texorpdfstring{pan\_posref}{pan\_posref}}
{\footnotesize\ttfamily \label{main_8cpp_a7ed3ad0733ad4ecedf22eb04235e7505} 
Share$<$int16\+\_\+t$>$ pan\+\_\+posref \{"{}panposref"{}\}}

\Hypertarget{main_8cpp_ad114459ce51573253fd6e470f90b2aec}\index{main.cpp@{main.cpp}!pan\_velocity\_pid@{pan\_velocity\_pid}}
\index{pan\_velocity\_pid@{pan\_velocity\_pid}!main.cpp@{main.cpp}}
\doxysubsubsection{\texorpdfstring{pan\_velocity\_pid}{pan\_velocity\_pid}}
{\footnotesize\ttfamily \label{main_8cpp_ad114459ce51573253fd6e470f90b2aec} 
PID pan\+\_\+velocity\+\_\+pid}

\Hypertarget{main_8cpp_a22f65a631b2d8634743b796fe8177a85}\index{main.cpp@{main.cpp}!pan\_vref@{pan\_vref}}
\index{pan\_vref@{pan\_vref}!main.cpp@{main.cpp}}
\doxysubsubsection{\texorpdfstring{pan\_vref}{pan\_vref}}
{\footnotesize\ttfamily \label{main_8cpp_a22f65a631b2d8634743b796fe8177a85} 
Share$<$int8\+\_\+t$>$ pan\+\_\+vref \{"{}panvref"{}\}}

\Hypertarget{main_8cpp_a8782c85d1bc81cddd908140fa492fbe6}\index{main.cpp@{main.cpp}!panencoder@{panencoder}}
\index{panencoder@{panencoder}!main.cpp@{main.cpp}}
\doxysubsubsection{\texorpdfstring{panencoder}{panencoder}}
{\footnotesize\ttfamily \label{main_8cpp_a8782c85d1bc81cddd908140fa492fbe6} 
\mbox{\hyperlink{class_encoder_task}{Encoder\+Task}} panencoder\+Task \& panencoder (\begin{DoxyParamCaption}\item[{\mbox{\hyperlink{main_8cpp_abdc6a0c3b4366410882e9b2728609e5a}{Pan\+ENCODER\+\_\+\+A\+\_\+\+GPIO}}}]{}{, }\item[{\mbox{\hyperlink{main_8cpp_a4d0ee5bdfb147d04624ac2d8aefbff46}{Pan\+ENCODER\+\_\+\+B\+\_\+\+GPIO}}}]{}{, }\item[{\mbox{\hyperlink{main_8cpp_a039cf14d1dd6ffcb54227fda70d740a6}{Pan\+ENCODER\+\_\+\+UNIT}}}]{}{}\end{DoxyParamCaption})}

\Hypertarget{main_8cpp_a000b34f09d3812c2177cbbc34e41bddc}\index{main.cpp@{main.cpp}!panmotor@{panmotor}}
\index{panmotor@{panmotor}!main.cpp@{main.cpp}}
\doxysubsubsection{\texorpdfstring{panmotor}{panmotor}}
{\footnotesize\ttfamily \label{main_8cpp_a000b34f09d3812c2177cbbc34e41bddc} 
\mbox{\hyperlink{class_motor_task}{Motor\+Task}} panmotor\+Task \& panmotor (\begin{DoxyParamCaption}\item[{\mbox{\hyperlink{main_8cpp_a4f5313f502282fbcfd79f30302a3c82b}{Pan\+IN1}}}]{}{, }\item[{\mbox{\hyperlink{main_8cpp_ad46c6e4ac5145a2506b854c28c625aa3}{Pan\+IN2}}}]{}{, }\item[{0}]{}{, }\item[{1}]{}{}\end{DoxyParamCaption})}

\Hypertarget{main_8cpp_a9a053dffceaa3d3bbddb421847244cd4}\index{main.cpp@{main.cpp}!tilt\_Cmd@{tilt\_Cmd}}
\index{tilt\_Cmd@{tilt\_Cmd}!main.cpp@{main.cpp}}
\doxysubsubsection{\texorpdfstring{tilt\_Cmd}{tilt\_Cmd}}
{\footnotesize\ttfamily \label{main_8cpp_a9a053dffceaa3d3bbddb421847244cd4} 
Share$<$uint8\+\_\+t$>$ tilt\+\_\+\+Cmd \{"{}tiltenc\+\_\+cmd"{}\}}
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

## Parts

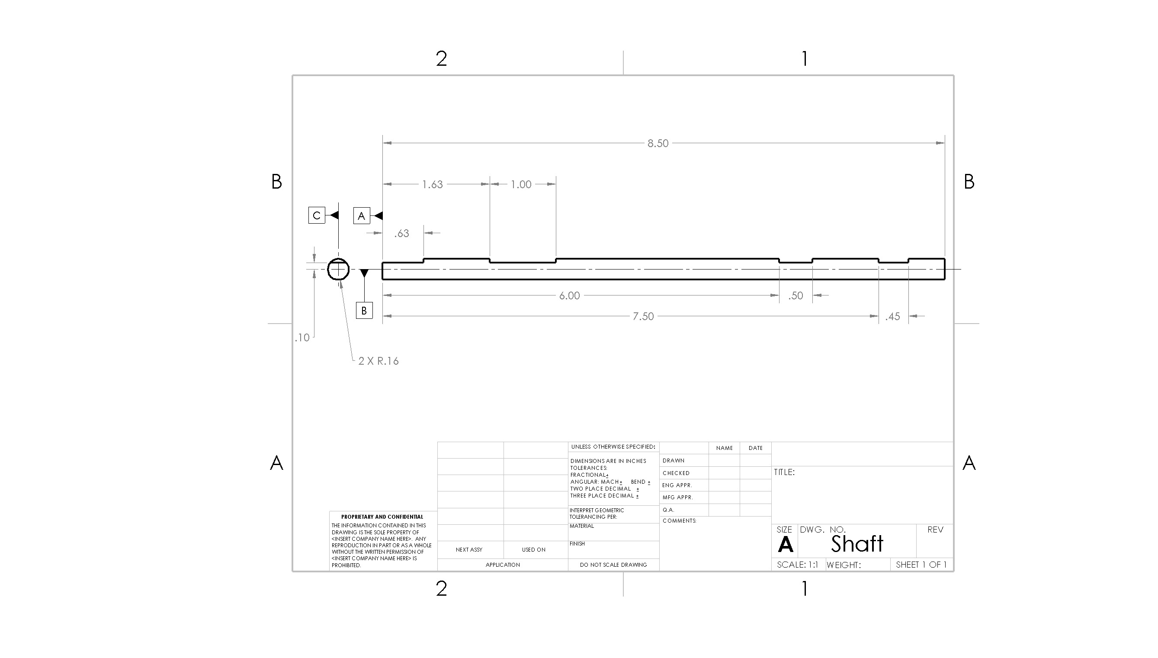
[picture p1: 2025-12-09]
hardware/cad/MechanicalParts/Shaft.JPG

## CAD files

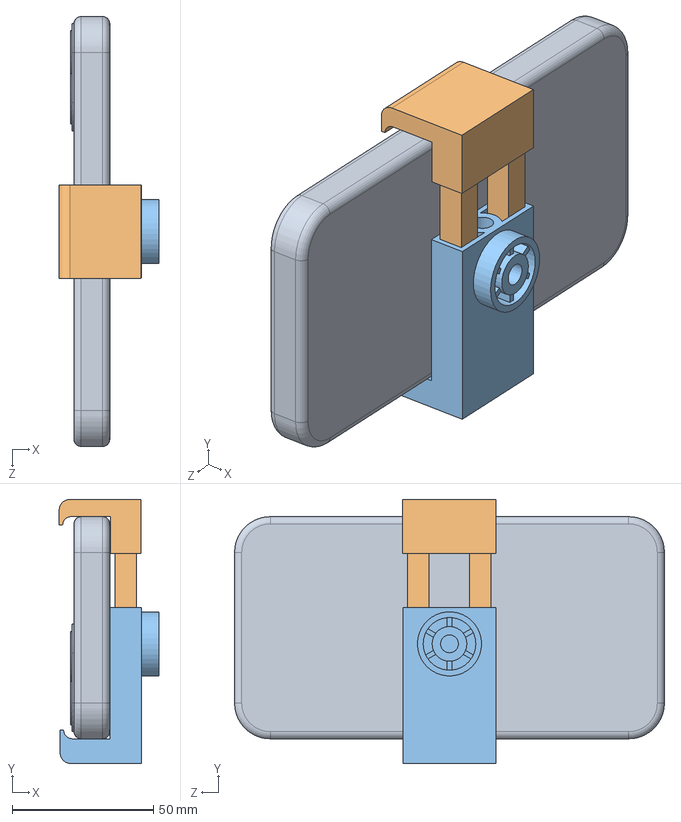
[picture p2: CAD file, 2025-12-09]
hardware/cad/Phone_Assembly/Phone_Assembly.SLDASM
35.4 x 93.6 x 152.4 mm
Phone_Mount
Phone_Mount2
phone

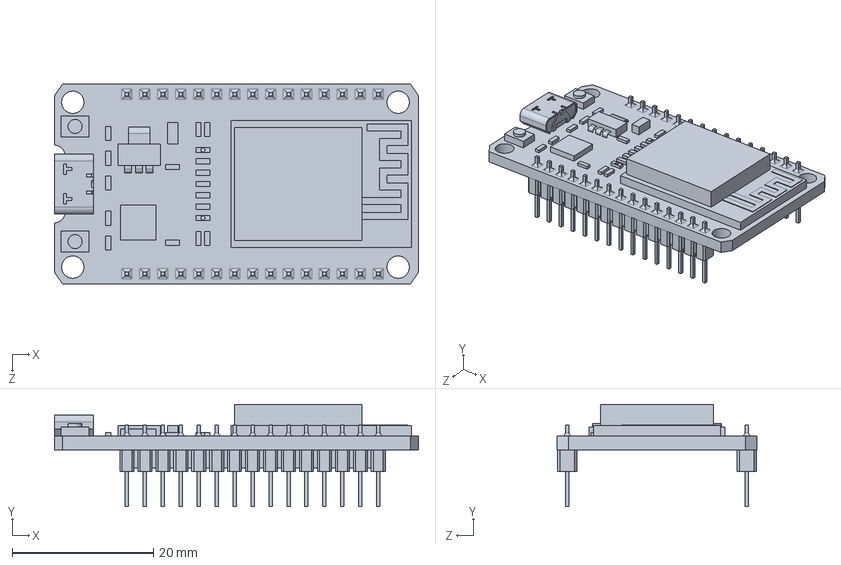
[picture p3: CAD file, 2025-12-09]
hardware/cad/ElectricalParts/ESP32.SLDPRT
51.5 x 14.5 x 28.3 mm

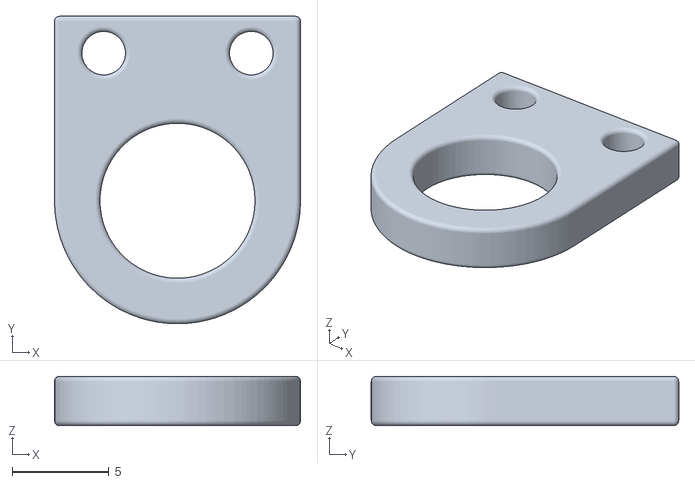
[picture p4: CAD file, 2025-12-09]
hardware/cad/Printed Parts/STLs/Filtermountcover.STL
12.7 x 15.9 x 2.54

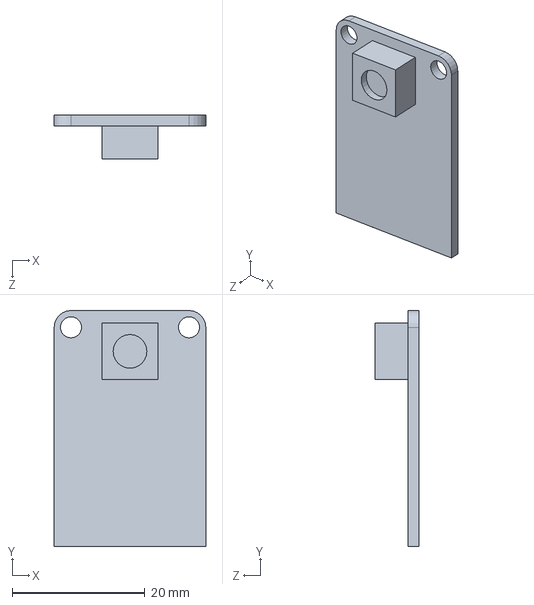
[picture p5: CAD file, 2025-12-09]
hardware/cad/ElectricalParts/OV5640.SLDPRT
22.9 x 35.6 x 6.61 mm

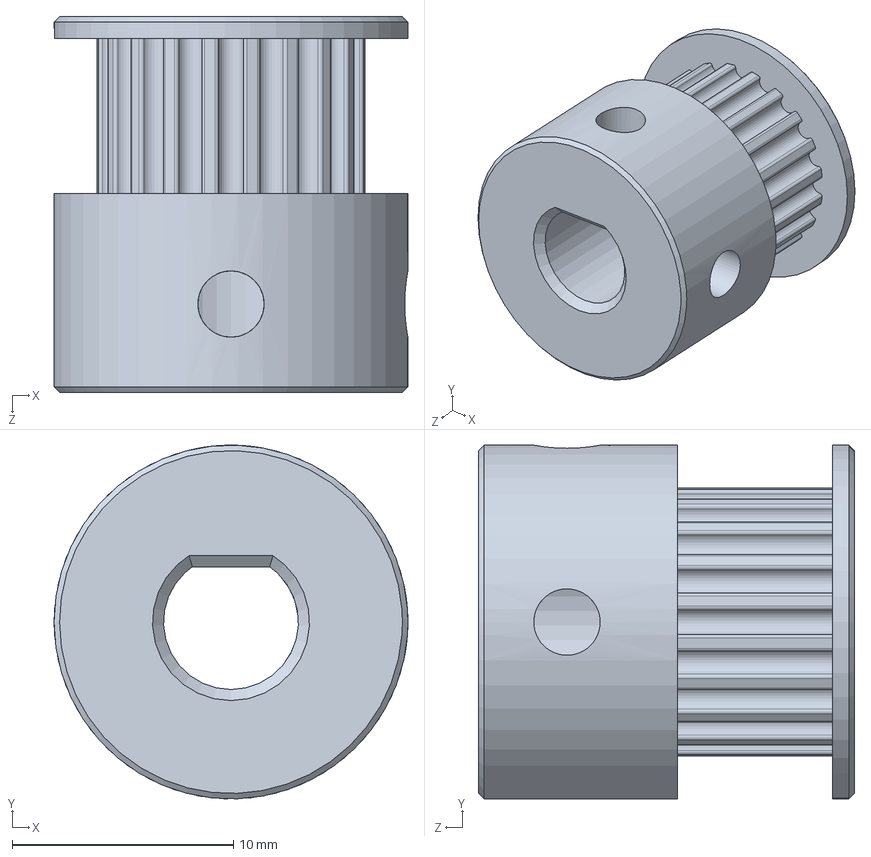
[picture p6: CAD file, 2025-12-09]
hardware/cad/MechanicalParts/GT2 Pulley 20 Tooth (ID6mm).SLDPRT
16.0 x 16.0 x 17.0 mm

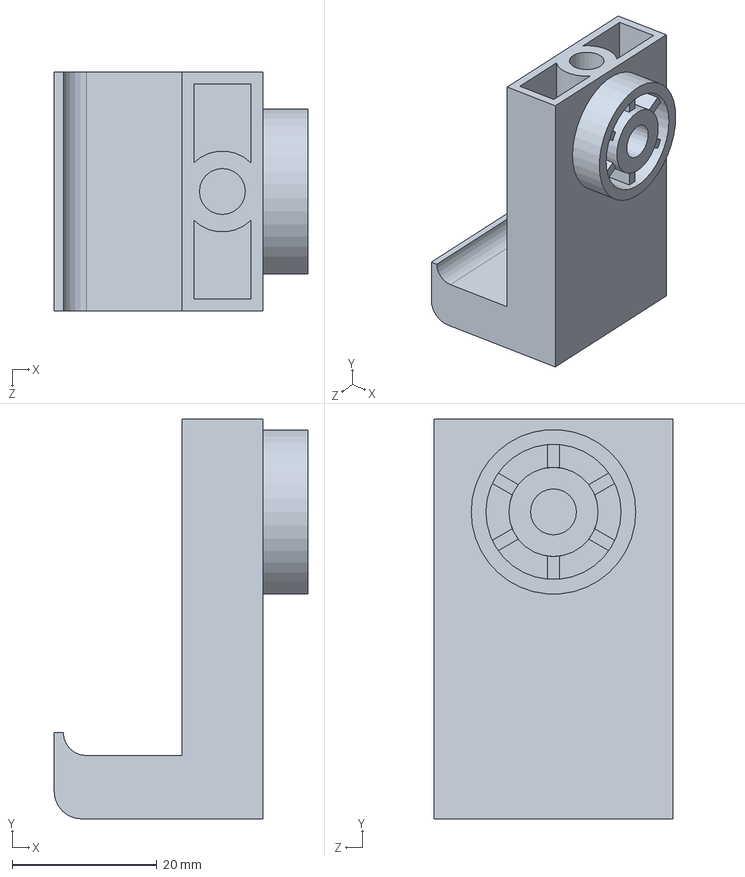
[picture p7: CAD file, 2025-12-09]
hardware/cad/Phone_Assembly/Phone_Mount.SLDPRT
35.1 x 55.2 x 33.0 mm

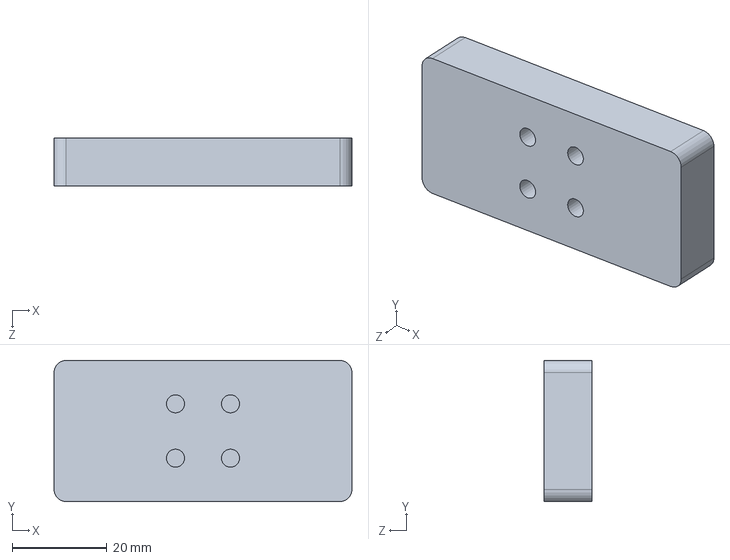
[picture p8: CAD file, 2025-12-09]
hardware/cad/Printed Parts/base mount.SLDPRT
62.7 x 29.7 x 10.2 mm

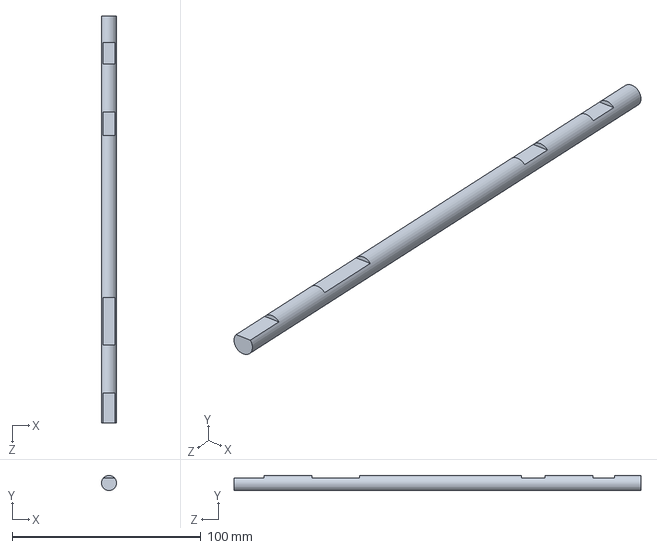
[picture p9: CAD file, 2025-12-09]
hardware/cad/MechanicalParts/Shaft.SLDPRT
8.00 x 8.00 x 215.9 mm

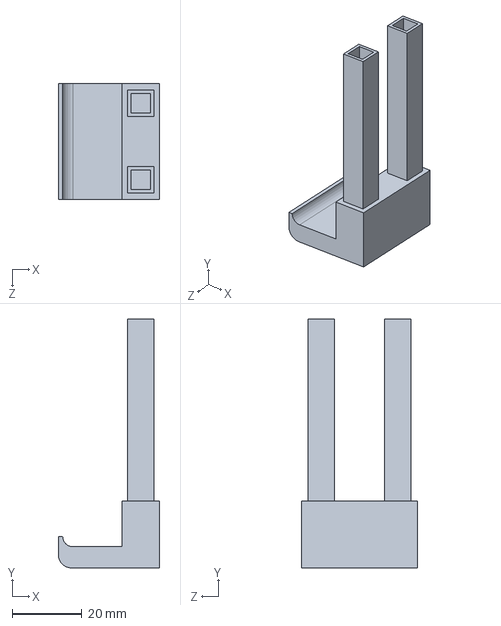
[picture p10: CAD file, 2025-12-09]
hardware/cad/Phone_Assembly/Phone_Mount2.SLDPRT
29.1 x 71.4 x 33.1 mm

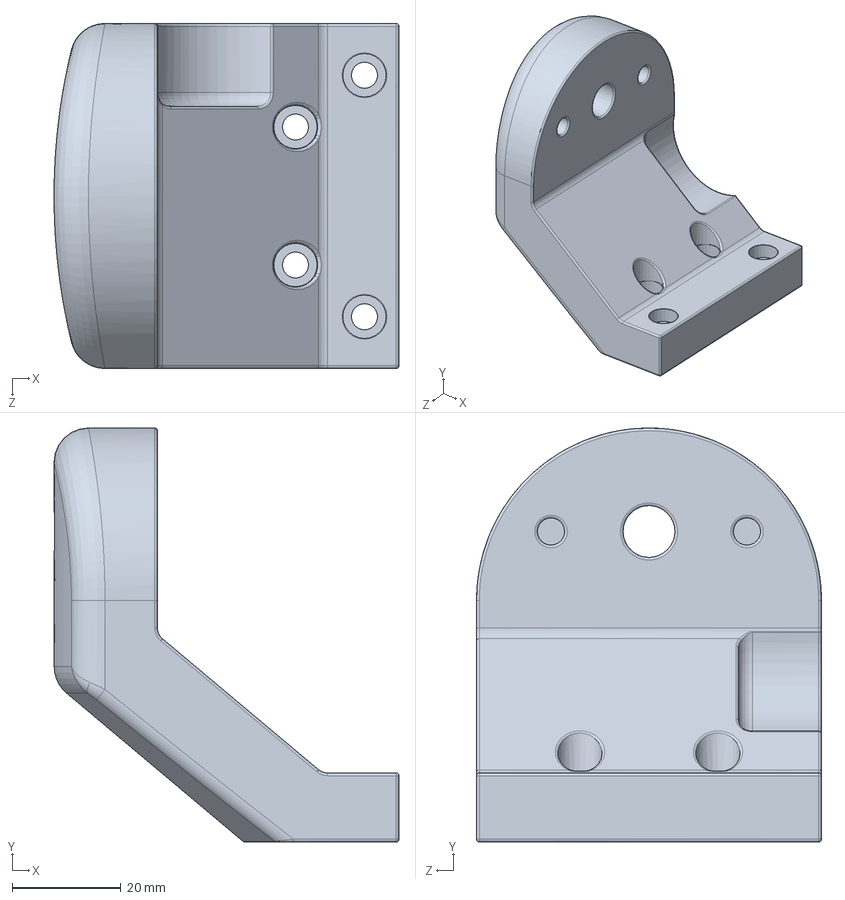
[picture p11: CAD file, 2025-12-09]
hardware/cad/Printed Parts/Tilt_Mount.SLDPRT
63.5 x 76.2 x 63.5 mm

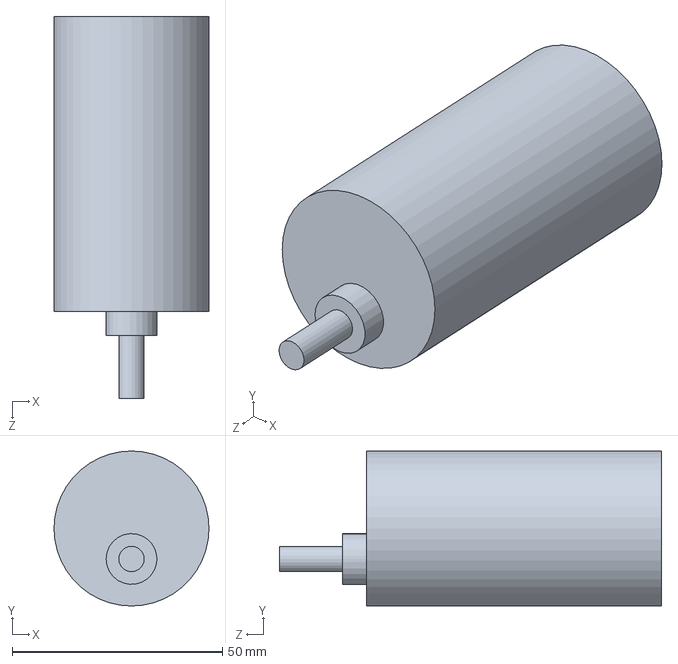
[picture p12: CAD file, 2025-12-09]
hardware/cad/ElectricalParts/Motor.SLDPRT
36.8 x 36.8 x 90.8 mm

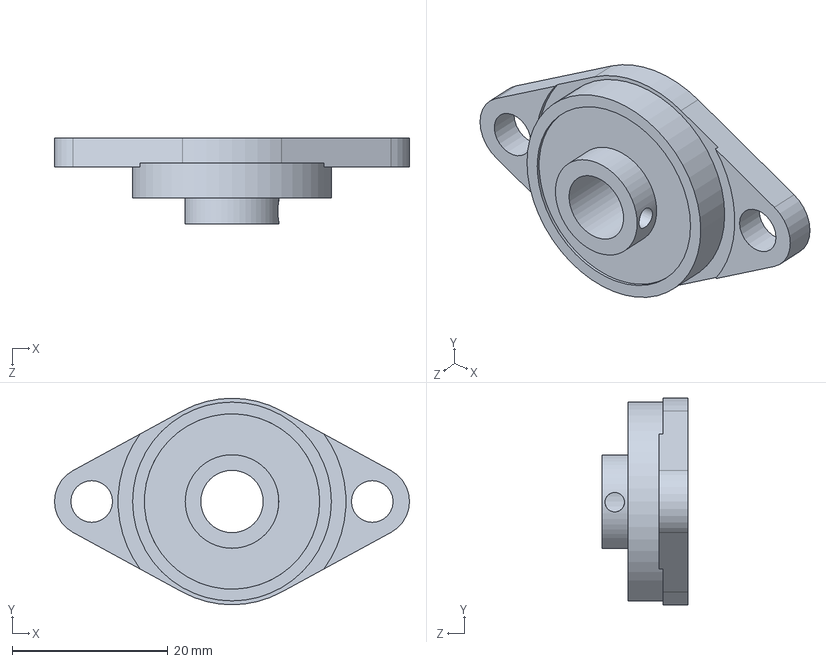
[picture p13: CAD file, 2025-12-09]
hardware/cad/MechanicalParts/8mm Bearing Mount.SLDPRT
45.6 x 26.5 x 11.0 mm

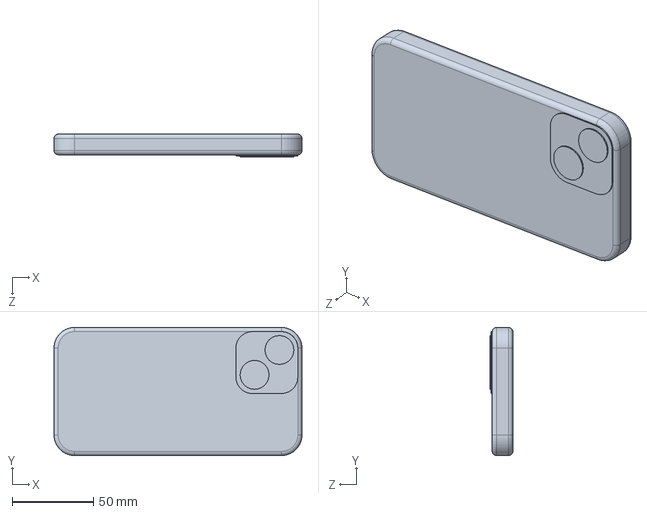
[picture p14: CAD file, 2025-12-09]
hardware/cad/Phone_Assembly/phone.SLDPRT
152.4 x 78.7 x 14.0 mm

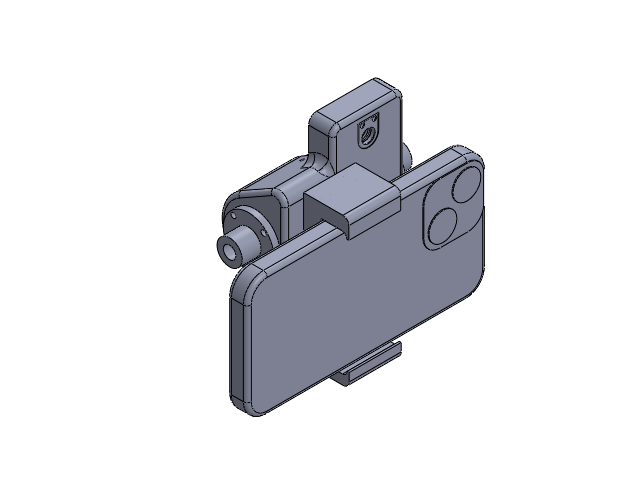
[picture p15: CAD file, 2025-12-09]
hardware/cad/Printed Parts/CameraPhoneMount.SLDASM
Tilt_Camera_Mount
Phone_Mount
Phone_Mount2
phone
OV5640
IRFilterMount
Filtermountcover
FlangedShaft_Collar x 2

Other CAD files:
hardware/cad/SportTrackr_Assembly.SLDASM
hardware/cad/ElectricalParts/sport_trackr_PCB.SLDASM
hardware/cad/ElectricalParts/CamFilter.SLDASM
hardware/cad/MechanicalParts/Shaft_Coupler.SLDPRT
hardware/cad/ElectricalParts/ESP32_BAT.SLDPRT
hardware/cad/ElectricalParts/Filtermountcover.SLDPRT
hardware/cad/ElectricalParts/MotorBat.SLDPRT
hardware/cad/MechanicalParts/30 THEETH 32MM GEAR.SLDPRT
hardware/cad/MechanicalParts/FlangedShaft_Collar.SLDPRT
hardware/cad/MechanicalParts/GT2_20T-sh8.SLDPRT
hardware/cad/MechanicalParts/Shaft.SLDDRW
hardware/cad/Printed Parts/Base.SLDPRT
hardware/cad/Printed Parts/Housing2.SLDPRT
hardware/cad/Printed Parts/IRCamHousingCover.SLDPRT
hardware/cad/Printed Parts/IRFilterMount.SLDPRT
hardware/cad/Printed Parts/STLs/Base.STL
hardware/cad/Printed Parts/STLs/Housing2.STL
hardware/cad/Printed Parts/STLs/IRFilterMount.STL
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

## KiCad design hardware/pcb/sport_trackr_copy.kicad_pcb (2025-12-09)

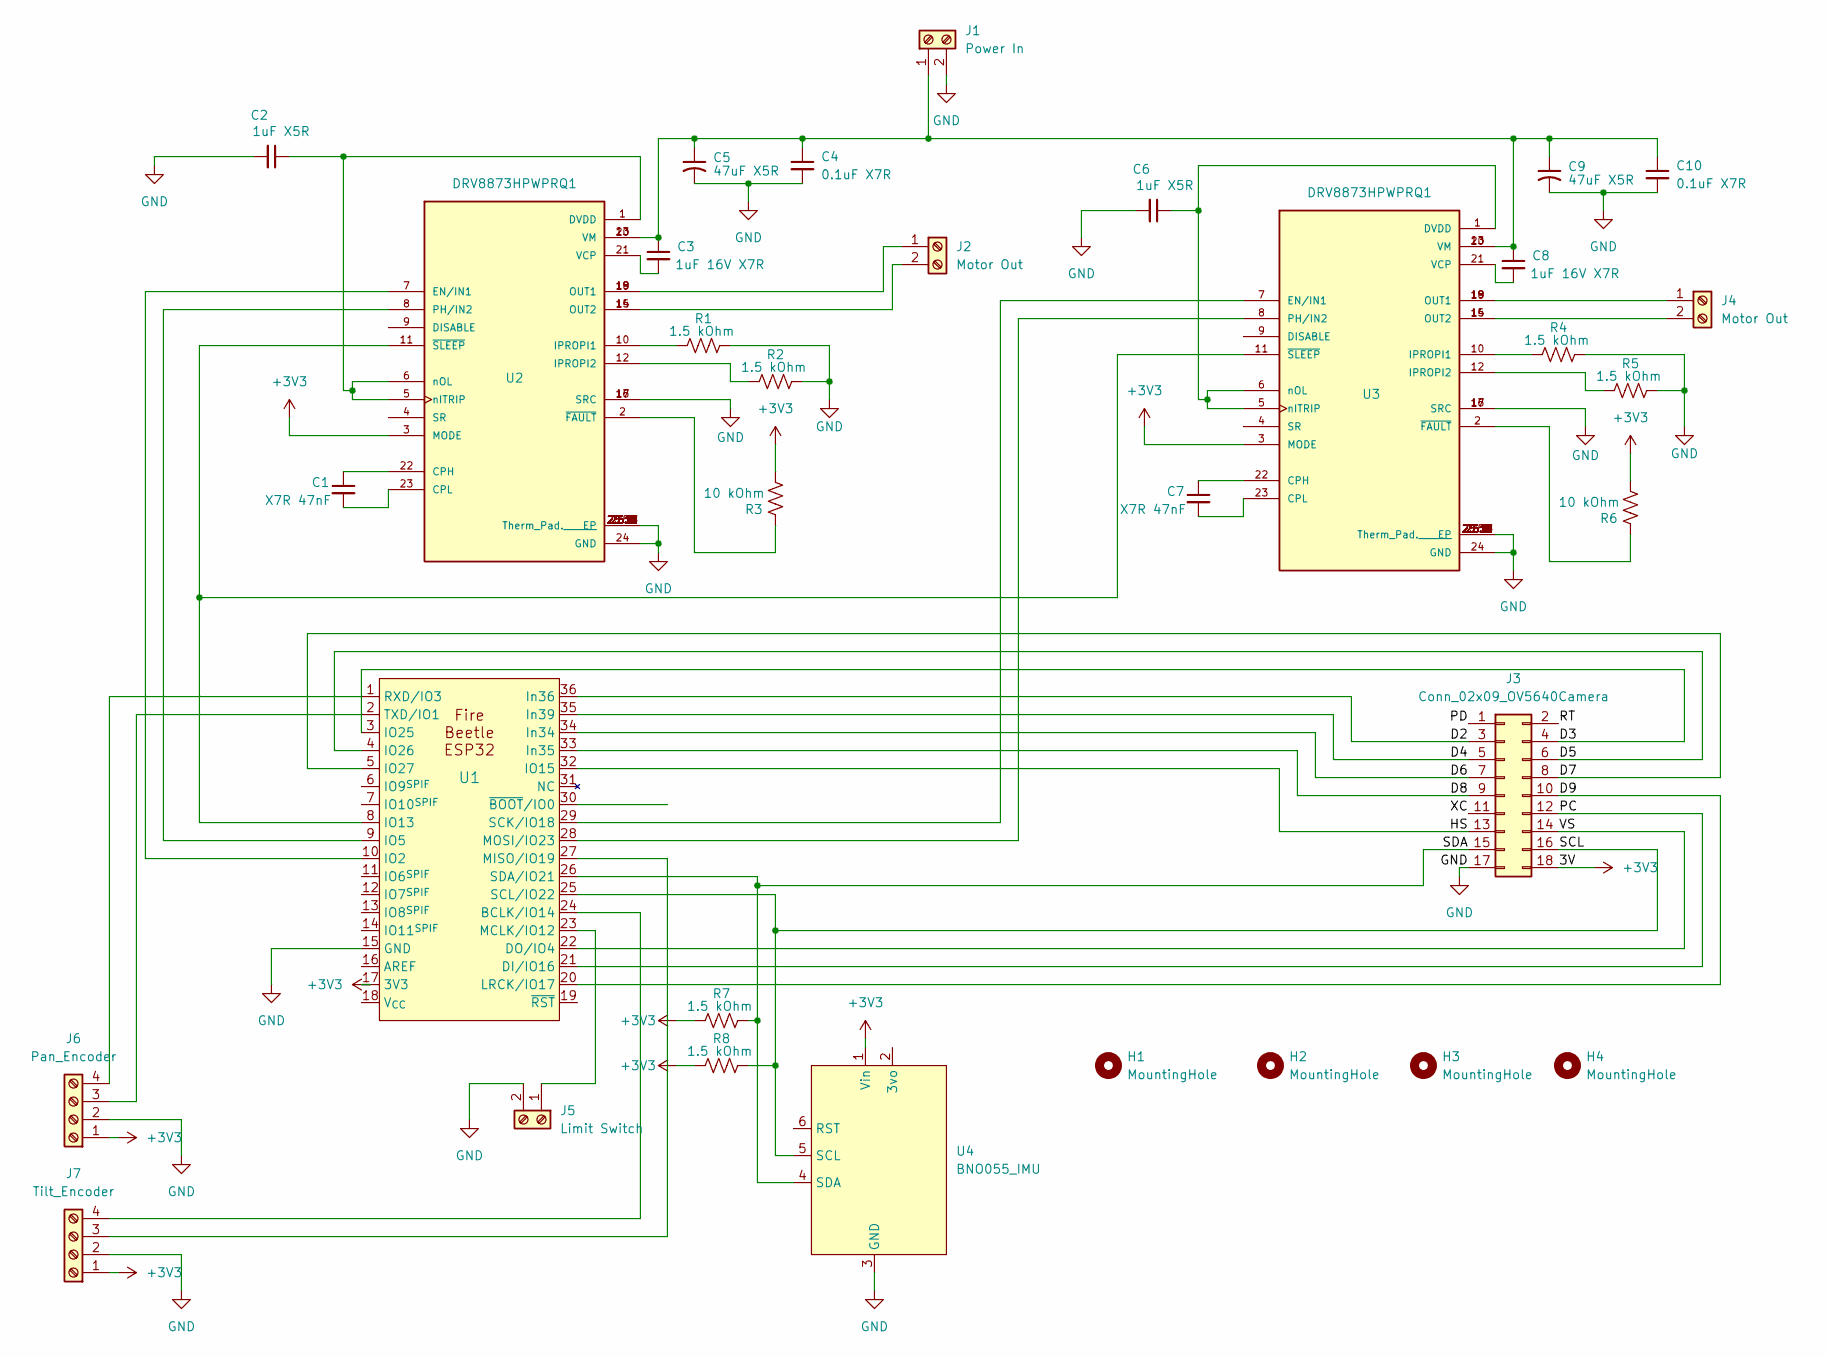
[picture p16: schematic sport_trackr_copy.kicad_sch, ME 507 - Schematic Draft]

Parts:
C1, C7: X7R 47nF; C_0805_2012Metric_Pad1.18x1.45mm_HandSolder
C2, C6: 1uF X5R; C_0805_2012Metric_Pad1.18x1.45mm_HandSolder
C3, C8: 1uF 16V X7R; C_0805_2012Metric_Pad1.18x1.45mm_HandSolder
C4, C10: 0.1uF X7R; C_0805_2012Metric_Pad1.18x1.45mm_HandSolder
C5, C9: 47uF X5R; C_1206_3216Metric_Pad1.33x1.80mm_HandSolder
H1, H2, H3, H4: MountingHole; MountingHole_3mm
J1: Power In; TerminalBlock_Phoenix_MKDS-1,5-2_1x02_P5.00mm_Horizontal
J2, J4: Motor Out; TerminalBlock_Phoenix_MKDS-1,5-2_1x02_P5.00mm_Horizontal
J3: Conn_02x09_OV5640Camera; PinHeader_2x09_P2.54mm_Vertical
J5: Limit Switch; TerminalBlock_Phoenix_MPT-0,5-2-2.54_1x02_P2.54mm_Horizontal
J6: Pan_Encoder; PinHeader_1x04_P2.54mm_Vertical
J7: Tilt_Encoder; PinHeader_1x04_P2.54mm_Vertical
R1, R2, R4, R5, R7, R8: 1.5 kOhm; R_0805_2012Metric_Pad1.20x1.40mm_HandSolder
R3, R6: 10 kOhm; R_0805_2012Metric_Pad1.20x1.40mm_HandSolder
U1: FireBeetle-ESP32
U2, U3: DRV8873HPWPRQ1; IC_DRV8873SPWPRQ1; PARTREV A
U4: BNO055_IMU; PinHeader_1x06_P2.54mm_Vertical

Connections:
+3V3: J3.18, J6.1, J7.1, R3.2, R6.2, R7.1, R8.1, U1.17 (3V3), U2.3 (MODE), U3.3 (MODE), U4.1 (Vin)
/D2: J3.3, U1.36 (In36)
/D3: J3.4, U1.3 (IO25)
/D4: J3.5, U1.35 (In39)
/D5: J3.6, U1.4 (IO26)
/D6: J3.7, U1.34 (In34)
/D7: J3.8, U1.5 (IO27)
/D8: J3.9, U1.33 (In35)
/D9: J3.10, U1.20 (LRCK/IO17)
/HS: J3.13, U1.32 (IO15)
/PC: J3.12, U1.21 (DI/IO16)
/PD: J3.1
/RT: J3.2
/SCL: J3.16, R8.2, U1.25 (SCL/IO22), U4.5 (SCL)
/SDA: J3.15, R7.2, U1.26 (SDA/IO21), U4.4 (SDA)
/VS: J3.14, U1.22 (DO/IO4)
/XC: J3.11
GND: C2.2, C4.2, C5.2, C6.2, C9.2, C10.2, J1.2, J3.17, J5.2, J6.2, J7.2, R1.2, R2.2, R4.2, R5.2, U1.15 (GND), U2.16 (SRC), U2.17 (SRC), U2.24 (GND), U2.25 (Therm_Pad.______), U2.25.1 (EP), U2.25.2 (EP), U2.25.3 (EP), U2.25.4 (EP), U2.25.5 (EP), U2.25.6 (EP), U2.25.7 (EP), U2.25.8 (EP), U2.25.9 (EP), U2.25.10 (EP), U2.25.11 (EP), U2.25.12 (EP), U2.25.13 (EP), U2.25.14 (EP), U2.25.15 (EP), U2.25.16 (EP), U2.25.17 (EP), U2.25.18 (EP), U3.16 (SRC), U3.17 (SRC), U3.24 (GND), U3.25 (Therm_Pad.______), U3.25.1 (EP), U3.25.2 (EP), U3.25.3 (EP), U3.25.4 (EP), U3.25.5 (EP), U3.25.6 (EP), U3.25.7 (EP), U3.25.8 (EP), U3.25.9 (EP), U3.25.10 (EP), U3.25.11 (EP), U3.25.12 (EP), U3.25.13 (EP), U3.25.14 (EP), U3.25.15 (EP), U3.25.16 (EP), U3.25.17 (EP), U3.25.18 (EP), U4.3 (GND)
unnamed: C3.1, C4.1, C5.1, C8.1, C9.1, C10.1, J1.1, U2.13 (VM), U2.20 (VM), U3.13 (VM), U3.20 (VM)
unnamed: J2.1, U2.18 (OUT1), U2.19 (OUT1)
unnamed: J2.2, U2.14 (OUT2), U2.15 (OUT2)
unnamed: J4.1, U3.18 (OUT1), U3.19 (OUT1)
unnamed: J4.2, U3.14 (OUT2), U3.15 (OUT2)
unnamed: J5.1, U1.23 (MCLK/IO12)
unnamed: J6.3, U1.2 (TXD/IO1)
unnamed: J6.4, U1.1 (RXD/IO3)
unnamed: J7.3, U1.27 (MISO/IO19)
unnamed: J7.4, U1.24 (BCLK/IO14)
unnamed: U1.10 (IO2), U2.7 (EN/IN1)
unnamed: U1.9 (IO5), U2.8 (PH/IN2)
unnamed: U1.8 (IO13), U2.11 (~SLEEP), U3.11 (~SLEEP)
unnamed: U1.28 (MOSI/IO23), U3.8 (PH/IN2)
unnamed: U1.29 (SCK/IO18), U3.7 (EN/IN1)
unnamed: C1.1, U2.22 (CPH)
unnamed: C1.2, U2.23 (CPL)
unnamed: C2.1, U2.1 (DVDD), U2.5 (nITRIP), U2.6 (nOL)
unnamed: R1.1, U2.10 (IPROPI1)
unnamed: R2.1, U2.12 (IPROPI2)
unnamed: C3.2, U2.21 (VCP)
unnamed: R3.1, U2.2 (~FAULT)
unnamed: C7.1, U3.22 (CPH)
unnamed: C7.2, U3.23 (CPL)
unnamed: C6.1, U3.1 (DVDD), U3.5 (nITRIP), U3.6 (nOL)
unnamed: R4.1, U3.10 (IPROPI1)
unnamed: R5.1, U3.12 (IPROPI2)
unnamed: C8.2, U3.21 (VCP)
unnamed: R6.1, U3.2 (~FAULT)

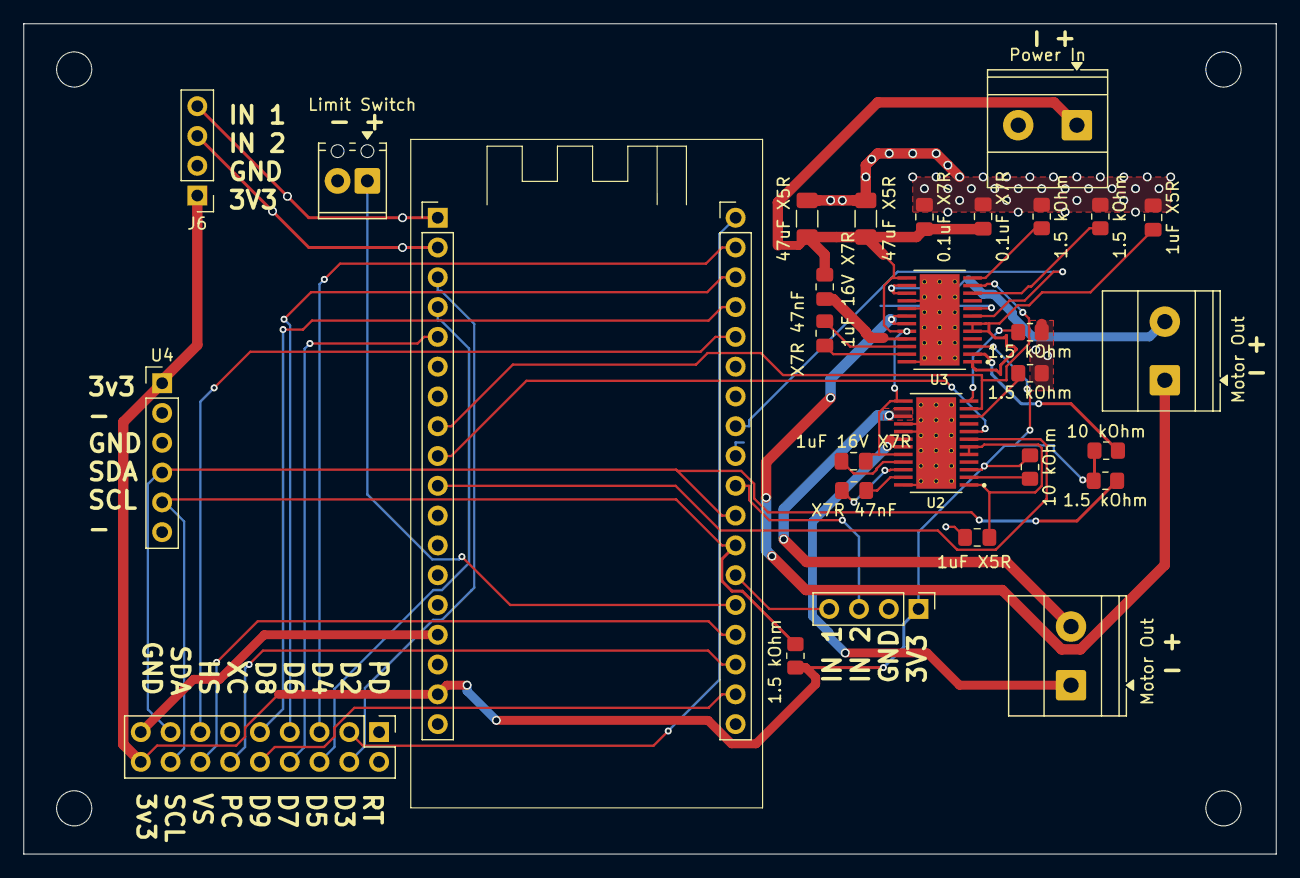
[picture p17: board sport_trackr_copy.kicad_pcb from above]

Board: 2 copper layers, 106.8 x 70.8 mm, 33 parts (0 on the bottom side), 44 nets.

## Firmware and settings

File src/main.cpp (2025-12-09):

/**
 * @file main.cpp
 * @brief Main application entry point for ESP32 camera-guided pan-tilt tracking system
 * 
 * This file implements a sophisticated multi-axis tracking system combining computer vision,
 * inertial measurement, and PID motor control. The system can automatically track LED targets
 * using camera feedback, provide manual teleoperation via web interface, and stream real-time
 * telemetry data including motor positions, IMU orientation, and tracking errors.
 * 
 * System Architecture:
 * -------------------
 * The system uses FreeRTOS multitasking to coordinate seven concurrent tasks:
 * 
 * 1. **MotorTask (Tilt & Pan)**: Multi-mode motor control (velocity, position, camera-based)
 * 2. **EncoderTask (Tilt & Pan)**: High-frequency position/velocity measurement via PCNT
 * 3. **ControllerTask**: Top-level FSM coordinating tracking modes and state transitions
 * 4. **CameraTask**: LED detection and visual servoing error computation
 * 5. **IMUTask**: BNO055 9-DOF orientation and motion sensing
 * 6. **UITask**: Web server, WebSocket telemetry, and command interface
 * 
 * Hardware Components:
 * -------------------
 * - ESP32-WROVER microcontroller (dual-core, WiFi, 8MB PSRAM)
 * - 2× DRV8833 dual H-bridge motor drivers
 * - 2× DC motors with 70:1 gearboxes
 * - 2× Quadrature encoders (64 CPR)
 * - OV5640 camera module (5MP, autofocus)
 * - BNO055 9-DOF IMU (accelerometer, gyroscope, magnetometer)
 * - Pan-tilt mechanical platform
 * 
 * Control Modes:
 * -------------
 * - **TRACKER**: Automatic LED tracking using camera feedback
 * - **TELEOP**: Manual control via web UI D-pad
 * - **MOTOR_TEST**: Open-loop motor testing for diagnostics
 * - **CALIBRATE**: Encoder homing and calibration sequence
 * 
 * PID Tuning Guide:
 * -----------------
 * Four independent PID controllers are available for tuning:
 * 
 * 1. **tilt_velocity_pid** - Tilt axis velocity control
 *    - Current: Kp=0.10, Ki=0.0, Kd=0.0
 *    - Tuning: Increase Kp for faster velocity response, add Ki to eliminate steady-state error
 * 
 * 2. **tilt_position_pid** - Tilt axis position control  
 *    - Current: Kp=0.080, Ki=0.0005, Kd=0.0
 *    - Tuning: Increase Kp for stiffer position hold, add Kd to reduce overshoot
 * 
 * 3. **pan_velocity_pid** - Pan axis velocity control
 *    - Current: Kp=0.10, Ki=0.0, Kd=0.0
 *    - Tuning: Adjust independently from tilt due to different mechanical characteristics
 * 
 * 4. **pan_position_pid** - Pan axis position control
 *    - Current: Kp=0.080, Ki=0.0005, Kd=0.0
 *    - Tuning: May need different gains than tilt due to gravity effects
 * 
 * To adjust gains, modify the Init() calls in setup():
 * ```cpp
 * tilt_velocity_pid.Init(Kp, Ki, Kd);
 * ```
 * 
 * Network Configuration:
 * ---------------------
 * - WiFi SSID/Password configured in UITask.cpp
 * - Web interface accessible at: http://<ESP32_IP_ADDRESS>
 * - WebSocket telemetry on same port as HTTP server
 * - Serial debug output at 115200 baud
 * 
 * Pin Assignments:
 * ---------------
 * See hardware configuration section in setup() for complete GPIO mapping:
 * - Motors: GPIO pins for DRV8833 IN1/IN2
 * - Encoders: GPIO pins for Phase A/B quadrature signals
 * - Camera: SPIO interface to OV5640
 * - IMU: I2C interface to BNO055
 * 
 * @author Motor Control Development Team
 * @date December 2025
 * @version 2.7
 * 
 * @see MotorTask.h for motor control implementation
 * @see CameraTask.h for computer vision details
 * @see ControllerTask.h for FSM state descriptions
 */

// ===== ESP32 Pan and Tilt Motor Control System with IMU Integration =====
#include <Arduino.h>
#include <cstdint>
#include "hardware/DRV883.h"
#include "tasks/MotorTask.h"
#include "hardware/Encoder.h"
#include "tasks/EncoderTask.h"
#include "tasks/UITask.h"
#include "tasks/IMU_Task.h"
#include <Wire.h>
#include "hardware/Adafruit_BNO055.h"
#include "tasks/CameraTask.h"
#include "tasks/ControllerTask.h"
#include "hardware/OV5640_camera.h"
// FreeRTOS APIs used to create tasks/queues
#include "freertos/FreeRTOS.h"
#include "freertos/task.h"
#include "freertos/queue.h"
// ME507 share utility
#include "taskshare.h"

// FreeRTOS task entry declared in MotorTask.cpp
extern "C" void ui_task_func(void* arg);
extern "C" void imu_task_func(void* arg);
extern "C" void controller_task_func(void* arg);
extern "C" void camera_task_func(void* arg);

/**
 * @brief FreeRTOS task entry point for tilt motor control
 * 
 * Dedicated task function for tilt axis motor control to avoid static instance
 * conflicts between pan and tilt MotorTask objects. Sets the static instance
 * pointer before each update to ensure correct object context.
 * 
 * Task Configuration:
 * - Update rate: 50ms (20Hz)
 * - Priority: Set during xTaskCreate() call
 * - Stack size: Configured in task creation
 * 
 * @param arg Pointer to tilt MotorTask object (cast from void*)
 * 
 * @note Separate task functions required because MotorTask uses static instance pattern
 * @note Instance pointer set before each update() call for correct FSM execution
 */
extern "C" void tilt_motor_task_func(void* arg) {
  MotorTask* motorTask = static_cast<MotorTask*>(arg);
  const TickType_t delayTicks = pdMS_TO_TICKS(50);
  for (;;) {
    if (motorTask) {
      MotorTask::set_instance(motorTask);  // Set instance before each update
      motorTask->update();
    }
    vTaskDelay(delayTicks);
  }
}

/**
 * @brief FreeRTOS task entry point for pan motor control
 * 
 * Dedicated task function for pan axis motor control, independent from tilt axis.
 * Maintains separate static instance context to prevent conflicts during concurrent
 * execution of both motor control tasks.
 * 
 * Task Configuration:
 * - Update rate: 50ms (20Hz)
 * - Priority: Set during xTaskCreate() call
 * - Stack size: Configured in task creation
 * 
 * @param arg Pointer to pan MotorTask object (cast from void*)
 * 
 * @note Must be separate from tilt_motor_task_func due to static instance pattern
 * @note Both motor tasks run concurrently without interference
 */
extern "C" void pan_motor_task_func(void* arg) {
  MotorTask* motorTask = static_cast<MotorTask*>(arg);
  const TickType_t delayTicks = pdMS_TO_TICKS(50);
  for (;;) {
    if (motorTask) {
      MotorTask::set_instance(motorTask);  // Set instance before each update
      motorTask->update();
    }
    vTaskDelay(delayTicks);
  }
}

/**
 * @brief FreeRTOS task entry point for tilt encoder monitoring
 * 
 * High-frequency task for tilt axis encoder position and velocity measurement.
 * Runs at 100Hz to minimize control loop latency and ensure accurate velocity
 * calculation via the Encoder's sliding window algorithm.
 * 
 * Task Configuration:
 * - Update rate: 10ms (100Hz)
 * - Priority: Typically higher than motor tasks for accurate feedback
 * - Stack size: Configured in task creation
 * 
 * @param arg Pointer to tilt EncoderTask object (cast from void*)
 * 
 * @note Fast update rate critical for control loop performance
 * @note Separate from pan encoder to avoid instance conflicts
 */
extern "C" void tilt_encoder_task_func(void* arg) {
  EncoderTask* encoderTask = static_cast<EncoderTask*>(arg);
  const TickType_t delayTicks = pdMS_TO_TICKS(10);
  for (;;) {
    if (encoderTask) {
      EncoderTask::set_instance(encoderTask);  // Set instance before each update
      encoderTask->update();
    }
    vTaskDelay(delayTicks);
  }
}

/**
 * @brief FreeRTOS task entry point for pan encoder monitoring
 * 
 * High-frequency task for pan axis encoder position and velocity measurement.
 * Operates independently from tilt encoder to provide concurrent feedback for
 * both axes without static instance conflicts.
 * 
 * Task Configuration:
 * - Update rate: 10ms (100Hz)
 * - Priority: Typically higher than motor tasks for accurate feedback
 * - Stack size: Configured in task creation
 * 
 * @param arg Pointer to pan EncoderTask object (cast from void*)
 * 
 * @note Matches tilt encoder update rate for consistent control behavior
 * @note Separate task function prevents static instance pointer conflicts
 */
extern "C" void pan_encoder_task_func(void* arg) {
  EncoderTask* encoderTask = static_cast<EncoderTask*>(arg);
  const TickType_t delayTicks = pdMS_TO_TICKS(10);
  for (;;) {
    if (encoderTask) {
      EncoderTask::set_instance(encoderTask);  // Set instance before each update
      encoderTask->update();
    }
    vTaskDelay(delayTicks);
  }
}

// ----------------Pin Declarations ----------------
// ----------------Pan Motor pins ----------------
#define PanIN1 GPIO_NUM_2
#define PanIN2 GPIO_NUM_5
#define nSLP_PIN GPIO_NUM_13
// ---------------- Pan Encoder pins/unit ----------------
#define TiltENCODER_A_GPIO GPIO_NUM_14
#define TiltENCODER_B_GPIO GPIO_NUM_19
#define TiltENCODER_UNIT   PCNT_UNIT_0
// ----------------Tilt Motor pins ----------------
#define TiltIN1 GPIO_NUM_18
#define TiltIN2 GPIO_NUM_23
// ---------------- Tilt Encoder pins/unit ----------------
#define PanENCODER_A_GPIO GPIO_NUM_3
#define PanENCODER_B_GPIO GPIO_NUM_1 //should be GPI01
#define PanENCODER_UNIT   PCNT_UNIT_1
// --------------------------------------------------

// ---------------- Hardware Objects ----------------
//Camera Object 
OV5640Camera camera = OV5640Camera(760);
// Motor: IN1/IN2 on LEDC channels 0 and 1
DRV883 panmotor(PanIN1, PanIN2, /*LEDC chs*/ 0, 1);
Encoder panencoder(PanENCODER_A_GPIO, PanENCODER_B_GPIO, PanENCODER_UNIT);
DRV883 tiltmotor(TiltIN1, TiltIN2, /*LEDC chs*/ 2, 3);
Encoder tiltencoder(TiltENCODER_A_GPIO, TiltENCODER_B_GPIO, TiltENCODER_UNIT);
// IMU instances (global so they can be accessed from loop)
TwoWire I2C = TwoWire(0);
Adafruit_BNO055 bno055_sensor = Adafruit_BNO055(1234, 0x28, &I2C);
// // --------------------------------------------------

// ---------------- Shares and Queues ----------------
//Camera Shares:
Share<int16_t> pan_err{"pan_err"};
Share<int16_t> tilt_err{"tilt_err"};
Share<bool> hasLed{"hasLed"};
Share<uint16_t> ledThreshold{"ledThreshold"};
Share<uint8_t> cam_Mode{"camMode"};
Share<uint8_t> UI_mode{"UI_mode"};
Share<bool> dcalibrate{"dcalibrate"};
// Encoder telemetry shares (declare BEFORE tasks that reference them)
Share<float> tilt_encPosition{"tiltenc_pos"};
Share<float> tilt_encVelocity{"tiltenc_vel"};
Share<float> pan_encPosition{"panenc_pos"};
Share<float> pan_encVelocity{"panenc_vel"};
// Motor reference (0-100)
// Motor reference (-100..100)
Share<int8_t> tilt_vref{"tiltvref"};
Share<int16_t> tilt_posref{"tiltposref"};
Share<int8_t> pan_vref{"panvref"};
Share<int16_t> pan_posref{"panposref"};
// Shared command for encoder/motor (0=STOP, 1=VELOCITY_RUN, 2=POSITION_RUN)
Share<uint8_t> tilt_Cmd{"tiltenc_cmd"};
Share<uint8_t> pan_Cmd{"panenc_cmd"};
// Shared zero flags for encoders
Share<bool> tilt_encZero{"tiltenc_zero"};
Share<bool> pan_encZero{"panenc_zero"};
// D-pad direction shares (-1, 0, 1)
Share<int8_t> dpad_pan{"dpad_pan"};
Share<int8_t> dpad_tilt{"dpad_tilt"};
// Motor test mode control (true = velocity control, false = position control)
Share<bool> motortest_mode{"motortest_mode"};
// IMU mode control (true = send IMU data, false = don't send)
Share<bool> imu_mode{"imu_mode"};
//shares for IMU
// where the 
Share<EulerAngles> g_eulerAngles{"euler_angles"};
Share<GyroData> g_gyroData{"gyro_data"};
Share<AccelData> g_accelData{"accel_data"};
// --------------------------------------------------

// ----------------   PID Objects   ----------------
// Create PID objects for independent gain tuning
PID tilt_velocity_pid;
PID tilt_position_pid;
PID pan_velocity_pid;
PID pan_position_pid;
// --------------------------------------------------

// ----------------   Task Objects   ----------------
//Camera task
CameraTask cameraTask(&camera, &pan_err, &tilt_err, &hasLed, &ledThreshold, &cam_Mode);
//Controller task
ControllerTask controllerTask(&pan_err, &tilt_err, &tilt_encPosition, &tilt_vref, &pan_vref, &tilt_Cmd, &pan_Cmd, &cam_Mode, &hasLed, &UI_mode, &dcalibrate, &dpad_pan, &dpad_tilt);
// MotorTask/EncoderTask/UITask instances (pass pointers to the above shares/queue)
MotorTask tiltmotorTask(&tiltmotor, &tilt_Cmd, &tilt_encVelocity, &tilt_vref, &tilt_encPosition, &tilt_posref, &tilt_velocity_pid, &tilt_position_pid, &tilt_err, true); 
EncoderTask tiltencoderTask(&tiltencoder, &tilt_encPosition, &tilt_encVelocity, &tilt_Cmd, &tilt_encZero);
MotorTask panmotorTask(&panmotor, &pan_Cmd, &pan_encVelocity, &pan_vref, &pan_encPosition, &pan_posref, &pan_velocity_pid, &pan_position_pid, &pan_err, false);
EncoderTask panencoderTask(&panencoder, &pan_encPosition, &pan_encVelocity, &pan_Cmd, &pan_encZero);
// MotorTask/EncoderTask/UITask instances (pass pointers to the above shares/queue)
UITask uiTask(&tilt_encPosition, &tilt_encVelocity, &tilt_vref, &tilt_posref, &tilt_Cmd, &tilt_encZero,
  &pan_encPosition, &pan_encVelocity, &pan_vref, &pan_posref, &pan_Cmd, &pan_encZero,
  &dpad_pan, &dpad_tilt, &imu_mode, &UI_mode, &motortest_mode, &dcalibrate, &g_eulerAngles, &g_gyroData, &g_accelData,
  &hasLed, &ledThreshold, &pan_err, &tilt_err);
IMUTask imuTask(&bno055_sensor, &g_eulerAngles, &g_gyroData, &g_accelData);

// ---------------------------------------------------

/**
 * @brief Arduino setup() - System initialization and FreeRTOS task creation
 * 
 * This function performs complete system initialization including hardware configuration,
 * communication interface setup, PID controller tuning, and FreeRTOS task creation.
 * All initialization must complete before tasks begin execution.
 * 
 * Initialization Sequence:
 * 1. Initialize all Share<T> objects to safe default values
 * 2. Configure serial communication (115200 baud)
 * 3. Connect telemetry queues between tasks
 * 4. Initialize I2C bus for IMU communication
 * 5. Initialize BNO055 IMU sensor and load calibration
 * 6. Initialize OV5640 camera module
 * 7. Enable motor drivers (nSLP pin HIGH)
 * 8. Configure PID controller gains for all four controllers
 * 9. Initialize WiFi Access Point and web server
 * 10. Create seven FreeRTOS tasks with appropriate priorities
 * 
 * Task Priority Scheme:
 * - Priority 5: Encoder tasks (highest - critical for control feedback)
 * - Priority 4: Camera task (high - visual servoing feedback)
 * - Priority 3: Controller task (medium-high - coordination)
 * - Priority 2: Motor tasks (medium - actuation)
 * - Priority 1: UI task (low - telemetry and commands)
 * - Priority 0: IMU task (lowest - supplementary data)
 * 
 * Hardware Configuration:
 * - I2C Bus: GPIO21 (SDA), GPIO22 (SCL) for IMU
 * - WiFi: Access Point mode "ESP32-MotorControl" / "motor123"
 * - Motor Enable: GPIO13 (nSLP_PIN) set HIGH
 * - Serial: 115200 baud for debug output
 * 
 * @note GPIO1 used by pan encoder (no USB Serial transmission)
 * @note Camera/IMU failures logged but don't halt system startup
 * @note All tasks start immediately after creation
 * @note setup() runs once on ESP32 core 1 before scheduler starts
 */
void setup() {
  // -------------------------------------------------------------------------
  // Step 1: Initialize All Share<T> Objects to Safe Defaults
  // -------------------------------------------------------------------------
  
  // Initialize all shares and queues
  pan_err.put(0);
  tilt_err.put(0);
  hasLed.put(false);
  ledThreshold.put(760);
  cam_Mode.put(0);
  UI_mode.put(0);
  dcalibrate.put(false);
  tilt_encPosition.put(0.0f);
  tilt_encVelocity.put(0.0f);
  pan_encPosition.put(0.0f);
  pan_encVelocity.put(0.0f);
  tilt_vref.put(0);
  tilt_posref.put(0);
  pan_vref.put(0);
  pan_posref.put(0);
  tilt_Cmd.put(0);
  pan_Cmd.put(0);
  tilt_encZero.put(false);
  pan_encZero.put(false);
  dpad_pan.put(0);
  dpad_tilt.put(0);
  motortest_mode.put(true);
  imu_mode.put(false);
  EulerAngles zero_angles = {0.0f, 0.0f, 0.0f};
  g_eulerAngles.put(zero_angles);
  GyroData zero_gyro = {0.0f, 0.0f, 0.0f};
  g_gyroData.put(zero_gyro);
  AccelData zero_accel = {0.0f, 0.0f, 0.0f};
  g_accelData.put(zero_accel);
  
  // -------------------------------------------------------------------------
  // Step 2: Initialize Serial Communication
  // -------------------------------------------------------------------------
  
  // Don't initialize Serial (USB) because GPIO1 is used for pan encoder
  Serial.begin(115200);
  delay(300);
  
  // -------------------------------------------------------------------------
  // Step 3: Connect Telemetry Queues Between Tasks
  // -------------------------------------------------------------------------
  
  // Connect encoder tasks to UITask telemetry queues
  tiltencoderTask.setTelemetryQueues(uiTask.getTiltVelQueue(), uiTask.getTiltPosQueue());
  panencoderTask.setTelemetryQueues(uiTask.getPanVelQueue(), uiTask.getPanPosQueue());
  // Connect camera task to UITask telemetry queue
  cameraTask.setTelemetryQueue(uiTask.getHasLedQueue());
  
  // -------------------------------------------------------------------------
  // Step 4: Serial Debug Messages
  // -------------------------------------------------------------------------
  
  // // Use Serial for all debug output instead (RX=GPIO0, TX=GPIO12)
  // Serial.begin(115200, SERIAL_8N1, 0, 12);
  delay(100);
  Serial.println("=== System Starting ===");
  Serial.println("Note: Using Serial for debug (GPIO1 used by pan encoder)");
  
  // -------------------------------------------------------------------------
  // Step 5: Initialize I2C Bus and IMU Sensor
  // -------------------------------------------------------------------------
  
  // Set I2C pins for ESP32
  I2C.setPins(21, 22);
  Serial.println("=== SporTrackr IMU Data Reader ===");
  Serial.println("Initializing IMU...");
  
  // Initialize and start IMU task
  if (imuTask.initIMU()) {
    Serial.println("IMU initialized successfully!");
    delay(300);
    
    // Load saved calibration offsets automatically
    Serial.println("Loading saved calibration offsets...");
    imuTask.loadSavedCalibration();
  } else {
    Serial.println("WARNING: IMU initialization failed!");
    Serial.println("Continuing without IMU...");
  }
  
  // -------------------------------------------------------------------------
  // Step 6: Initialize OV5640 Camera Module
  // -------------------------------------------------------------------------
  
  // Camera initialization - skip if it fails (GPIO conflicts)
  bool camera_ok = camera.begin();
  if (!camera_ok) {
    Serial.println("WARNING: Camera initialization failed!");
    Serial.println("Continuing without camera...");
  } else {
    Serial.println("Camera initialized successfully");
  }
  
  // -------------------------------------------------------------------------
  // Step 7: Enable Motor Drivers
  // -------------------------------------------------------------------------
  
  // Enable motors by setting nSLP (not-sleep) pin HIGH
  pinMode(nSLP_PIN, OUTPUT);
  digitalWrite(nSLP_PIN, HIGH);
  
  // -------------------------------------------------------------------------
  // Step 8: Initialize PID Controllers with Tuned Gains
  // -------------------------------------------------------------------------
  
  // Initialize PID controllers with tuned gains
  // Tilt motor PIDs
  tilt_velocity_pid.Init(0.30, 0.0, 0.0);      // Kp=0.10 for velocity control
  tilt_position_pid.Init(0.150, 0.005, 0.0);  // Kp=0.080, Ki=0.0005 for position control
  
  // Pan motor PIDs
  pan_velocity_pid.Init(0.10, 0.0, 0.0);       // Kp=0.10 for velocity control
  pan_position_pid.Init(0.150, 0.005, 0.0);   // Kp=0.080, Ki=0.0005 for position control
  
  Serial.println("PID controllers initialized");
  
  // -------------------------------------------------------------------------
  // Step 9: Initialize WiFi Access Point and Web Server
  // -------------------------------------------------------------------------
  
  // Initialize ESP32 as WiFi Access Point (much easier than connecting to existing networks!)
  // The ESP32 will create its own hotspot that you can connect to from any device
  uiTask.initWebServer("ESP32-MotorControl", "motor123");
  Serial.println("UITask web server initialized as Access Point");

  // -------------------------------------------------------------------------
  // Step 10: Create FreeRTOS Tasks
  // -------------------------------------------------------------------------
  
  // Start Motor task (50 ms tick in its own entry function)
  // Start Tilt Motor task
  xTaskCreate(
    tilt_motor_task_func,
    "TiltMotorTask",
    2048,
    &tiltmotorTask,
    2,
    nullptr
  );
  // Start Tilt Encoder task
  xTaskCreate(
    tilt_encoder_task_func,
    "TiltEncoderTask",
    2048,
    &tiltencoderTask,
    5,
    nullptr
  );
  // Start Pan Motor task
  xTaskCreate(
    pan_motor_task_func,
    "PanMotorTask",
    2048,
    &panmotorTask,
    2,
    nullptr
  );
  // Start Pan Encoder task
  xTaskCreate(
    pan_encoder_task_func,
    "PanEncoderTask",
    2048,
    &panencoderTask,
    5,
    nullptr
  );
  // Start UI task
  xTaskCreate(
    ui_task_func,
    "UITask",
    8192,  // Increased from 4096 for WebSocket telemetry broadcasting
    &uiTask,
    1,
    nullptr
  );
  //Start IMU task (disabled - I2C errors)
  xTaskCreate(
    imu_task_func,
    "IMUTask",
    4096,
    &imuTask,
    0,
    nullptr
  );
  // Start Controller task
  xTaskCreate(
    controller_task_func,
    "ControllerTask",
    2048,
    &controllerTask,
    3,
    nullptr
  );
  //Start Camera task (temporarily disabled to debug GPIO conflict)
  xTaskCreate(
    camera_task_func,
    "CameraTask",
    4096,
    &cameraTask,
    4,
    nullptr
  );

 }
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
void loop() {
  // Idle; tasks run under FreeRTOS
  delay(600000000);
}

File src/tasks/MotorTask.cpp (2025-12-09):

/**
 * @file MotorTask.cpp
 * @brief Implementation of motor control task with velocity, position, and camera-based control modes
 * 
 * This file implements a comprehensive motor control system with multiple control modes:
 * - WAIT: Idle state with motor braked
 * - VRUN: Velocity control with feedforward and stiction compensation
 * - PRUN: Position control using PID with anti-windup
 * - CAMERA_PRUN: Camera error-based position control for visual tracking
 * 
 * Features include:
 * - Independent PID controllers for velocity and position control
 * - Tilt motor position clamping for safety (-150° to +10°)
 * - Stiction compensation to overcome static friction
 * - Dynamic state transitions based on command shares
 * 
 * @author Motor Control Development Team
 * @date December 2025
 * @version 3.0
 */

#include "MotorTask.h"
#include <Arduino.h>
#include "freertos/FreeRTOS.h"
#include "freertos/task.h"

/// Static instance pointer for C-style callback functions
MotorTask* MotorTask::instance_ = nullptr;

/**
 * @brief Constructor for MotorTask
 * 
 * Initializes motor control task with all necessary shares and PID controllers.
 * PID controllers are externally managed to allow independent tuning per motor.
 * 
 * @param motor Pointer to DRV883 motor driver object
 * @param cmdShare Command share (0=WAIT, 1=VRUN, 2=PRUN, 3=CAMERA_PRUN)
 * @param veloShare Current velocity feedback share (deg/s)
 * @param vref Velocity reference share (desired velocity, deg/s)
 * @param posShare Current position feedback share (degrees)
 * @param posref Position reference share (desired position, degrees)
 * @param velocity_pid Pointer to velocity PID controller (externally managed)
 * @param position_pid Pointer to position PID controller (externally managed)
 * @param cameraErr Camera pixel error share for CAMERA_PRUN mode
 * @param isTiltMotor True if this is the tilt motor (enables position clamping)
 */
MotorTask::MotorTask(DRV883* motor,
                     Share<uint8_t>* cmdShare,
                     Share<float>* veloShare,
                     Share<int8_t>* vref, 
                     Share<float>* posShare,
                     Share<int16_t>* posref,
                     PID* velocity_pid,
                     PID* position_pid,
                     Share<int16_t>* cameraErr,
                     bool isTiltMotor) noexcept
  : motor_(motor),
    cmdShare_(cmdShare),
    veloShare_(veloShare),
    vref_(vref),
    posShare_(posShare),
    posref_(posref),
    velocity_pid_(velocity_pid),
    position_pid_(position_pid),
    cameraErr_(cameraErr),
    isTiltMotor_(isTiltMotor),
    fsm_(states_, 4)
{
  // Don't set instance_ here - will be set by task function
  // PID controllers are initialized externally and passed in

}
// ============================================================================
// State Machine Implementation
// ============================================================================

/**
 * @brief WAIT state - Motor idle and stopped
 * 
 * In this state, the motor is kept braked and waiting for commands.
 * Monitors the command share for state transition requests:
 * - Command 1: Transition to VRUN (velocity control)
 * - Command 2: Transition to PRUN (position control)  
 * - Command 3: Transition to CAMERA_PRUN (camera-based position control)
 * - Command 0 or other: Stay in WAIT
 * 
 * @return Next state ID to transition to
 * @retval WAIT Stay in wait state
 * @retval VRUN Transition to velocity control
 * @retval PRUN Transition to position control
 * @retval CAMERA_PRUN Transition to camera-based control
 */
uint8_t MotorTask::exec_wait() noexcept {
  if (!instance_) return -1;

  // Always keep motor stopped while waiting
  if (instance_->motor_) instance_->motor_->brake();

  // Read latest command from the shared command variable (if present).
  if (instance_->cmdShare_) {
    uint8_t cmd = instance_->cmdShare_->get();
    if (cmd == static_cast<int8_t>(1)) { // VELOCITY_RUN
      Serial.println("[MotorTask] Received VELOCITY_RUN command, transitioning to VRUN state");
      return static_cast<int>(VRUN);  
    }  
    else if (cmd == static_cast<int8_t>(2)) { // POSITION_RUN
      Serial.println("[MotorTask] Received POSITION_RUN command, transitioning to PRUN state");
      return static_cast<int>(PRUN);
    }
    else if (cmd == static_cast<int8_t>(3)) { // CAMERA_PRUN
      Serial.println("[MotorTask] Received CAMERA_PRUN command, transitioning to CAMERA_PRUN state");
      return static_cast<int>(CAMERA_PRUN);
    }
    // STOP/other -> stay in WAIT
  }
  return static_cast<int>(WAIT);
}

/**
 * @brief VRUN state - Velocity control with stiction compensation
 * 
 * Implements open-loop velocity control with the following features:
 * - Position-based safety limits for tilt motor (-150° to +10°)
 * - Directional clamping (only stops motion going further out of bounds)
 * - Stiction compensation to overcome static friction
 * - Dynamic state transitions based on command updates
 * 
 * Control Algorithm:
 * 1. Read desired velocity from vref share
 * 2. Check tilt motor position limits if applicable
 * 3. Add stiction compensation (30 for tilt, 0 for pan)
 * 4. Apply motor effort directly (open-loop control)
 * 
 * @return Next state ID to transition to
 * @retval VRUN Continue velocity control
 * @retval WAIT Stop motors
 * @retval PRUN Switch to position control
 * @retval CAMERA_PRUN Switch to camera-based control
 * 
 * @note Currently uses open-loop control (PID code commented out)
 * @note Stiction compensation adds baseline effort to overcome static friction
 */
uint8_t MotorTask::exec_velorun() noexcept {
  if (!instance_) return -1;

  // -------------------------------------------------------------------------
  // Step 1: Position Safety Checks for Tilt Motor
  // -------------------------------------------------------------------------
  
  // Get current position for clamping
  float current_position = 0.0f;
  if (instance_->posShare_) {
    current_position = instance_->posShare_->get();
  }

  // Get desired velocity for clamping check
  float desired_velocity = 0.0f;
  if (instance_->vref_) {
    desired_velocity = static_cast<float>(instance_->vref_->get());
  }
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

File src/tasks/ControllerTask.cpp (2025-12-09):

/**
 * @file ControllerTask.cpp
 * @brief Implementation of top-level FSM controller for LED tracking and manual control
 * 
 * This file implements a sophisticated multi-mode controller that coordinates camera-based
 * LED tracking, manual teleoperation, motor testing, and calibration. The task acts as the
 * system supervisor, managing state transitions and motor command generation.
 * 
 * State Machine Details:
 * - **CALIBRATE**: Homes motors to known positions using encoder feedback
 * - **WAIT**: Idle state with motors stopped
 * - **SCAN**: Sweeping search pattern when LED not detected
 * - **TRACKR**: Active tracking using camera pixel errors for PID control
 * - **TELEOP**: Manual D-pad control from web UI
 * - **MOTOR_TEST**: Open-loop testing for diagnostics
 * 
 * Tracking Behavior:
 * - Uses camera pixel errors (pan_err, tilt_err) from LED detection
 * - LED loss handled with 5-frame persistence counter before switching to SCAN
 * - Automatic recovery to TRACKR when LED redetected during SCAN
 * - Position limits enforced on tilt axis for mechanical safety
 * 
 * Motor Command Generation:
 * - Sets motor modes: 0=WAIT, 1=VRUN, 2=PRUN, 3=CAMERA_PRUN
 * - Updates velocity setpoints for VRUN and TELEOP modes
 * - Updates camera errors for CAMERA_PRUN tracking mode
 * 
 * @author Control Systems Team
 * @date November 2025
 * @version 2.1
 * 
 * @see ControllerTask.h for class interface and mode descriptions
 * @see MotorTask.h for motor control implementation details
 */

#include <Arduino.h>
#include "ControllerTask.h"
#include "taskshare.h"
#include "PID.h"

/// @brief Static instance pointer for FSM callback access
ControllerTask* ControllerTask::instance_ = nullptr;

/**
 * @brief Construct controller task with all necessary data shares
 * 
 * Initializes the controller task with pointers to all shared data containers
 * used for inter-task communication. Sets up FSM with all six states and
 * initializes LED loss tracking.
 * 
 * @param pan_err Camera pan error share (pixels from image center)
 * @param tilt_err Camera tilt error share (pixels from image center)
 * @param tiltpos Current tilt position share (degrees from encoder)
 * @param tiltVelo Tilt velocity command share (-100 to 100)
 * @param panVelo Pan velocity command share (-100 to 100)
 * @param tilt_mode Tilt motor mode command (0=WAIT, 1=VRUN, 2=PRUN, 3=CAMERA_PRUN)
 * @param pan_mode Pan motor mode command (0=WAIT, 1=VRUN, 2=PRUN, 3=CAMERA_PRUN)
 * @param Cam_mode Camera mode control share
 * @param hasLed LED detection status share (true when LED visible)
 * @param UI_mode User interface mode selection share
 * @param dcalibrate Calibration trigger share (true to start calibration)
 * @param dpad_pan D-pad pan direction (-1=left, 0=none, 1=right)
 * @param dpad_tilt D-pad tilt direction (-1=down, 0=none, 1=up)
 * @param updateMs FSM update period in milliseconds (default 100ms = 10Hz)
 */
ControllerTask::ControllerTask(Share<int16_t>* pan_err,
                                       Share<int16_t>*  tilt_err,
                                       Share<float_t>*  tiltpos,
                                       Share<int8_t>*  tiltVelo,
                                       Share<int8_t>*  panVelo,
                                       Share<uint8_t>* tilt_mode,
                                       Share<uint8_t>* pan_mode,
                                       Share<uint8_t>* Cam_mode,
                                       Share<bool>*       hasLed,
                                       Share<uint8_t>*   UI_mode,
                                       Share<bool>*   dcalibrate,
                                       Share<int8_t>*  dpad_pan,
                                       Share<int8_t>*  dpad_tilt,
                                       uint32_t updateMs) noexcept
  : updateMs_(updateMs),
    pan_err_(pan_err),
    tilt_err_(tilt_err),
    tiltpos_(tiltpos),
    tiltVelo_(tiltVelo),
    panVelo_(panVelo),
    tilt_mode_(tilt_mode),
    pan_mode_(pan_mode),
    Cam_mode_(Cam_mode),
    hasLed_(hasLed),
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

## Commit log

2025-11-13 Initial commit: MotorEncoderUI PlatformIO project with encoder, motor, and UI tasks
2025-11-14 Implement position control with PID and fix command conflicts
    Major changes:
    - Add PID controllers to MotorTask for velocity and position control
    - Implement position control state machine in MotorTask
    - Convert position data type from int32_t to float throughout codebase
    - Fix encoder overflow detection and add GPIO pull-ups
    - Add two-step UI (mode selection then value input) in UITask
    - Fix command conflict between EncoderTask and MotorTask (ZERO now cmd 3)
    - Add extensive debug output for motor control troubleshooting
    - Create data/ directory for future web interface
    Fixes:
    - Encoder wrap detection at 32768 boundaries
    - Position control immediately stopping due to command conflicts
    - Typ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
    [Encoder.cpp, EncoderTask.cpp, MotorTask.cpp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]
2025-11-21 Add comprehensive Doxygen documentation and BNO055 IMU integration
    Major improvements:
    - Added detailed Doxygen documentation throughout all source files
    - Integrated BNO055 IMU sensor with FSM-based task architecture
    - Added real-time IMU telemetry to web interface (Euler angles, gyroscope, accelerometer)
    - Converted IMU data sharing from arrays to structs for Share<T> compatibility
    - Enhanced web interface with separated HTML/CSS/JS files for maintainability
    - Fixed compilation issues with proper includes and type definitions
    - Added comprehensive file headers with technical specifications and usage examples
    - Improved code organization and cross-references between components
    Technical ad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
    [DRV883.cpp, Encoder.cpp, IMU_TASK.cpp]
2025-11-24 Added camera support with OV5640 Class and CameraTask files
2025-11-25 Added PID controller task for camera following
2025-11-25 duplicated motor and encoder objects to implement both tilt and pan control
2025-12-01 print statements indicating entry into CALIBRATE a nd MOTOR_TEST states
2025-12-09 Organizing for the repository 'motor-encoder-ui'
2025-12-09 organizing the repo moving the pcb into main
    [30 THEETH 32MM GEAR.SLDPRT, 8mm Bearing Mount.SLDPRT, Base.SLDPRT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]
2025-12-09 Changing the cad files directory structure to be more organized
    [30 THEETH 32MM GEAR.SLDPRT, 8mm Bearing Mount.SLDPRT, Base.SLDPRT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]
2025-12-09 moved pcb files into the pcb folder
    [sport_trackr_copy.kicad_pcb, sport_trackr_copy.kicad_sch]
2025-12-09 Add link to Adafruit BNO055 driver in README
    Updated the README to include a link for the Adafruit BNO055 driver.
2025-12-10 Revise motor usage examples and formatting
    Updated usage examples and corrected text formatting.
